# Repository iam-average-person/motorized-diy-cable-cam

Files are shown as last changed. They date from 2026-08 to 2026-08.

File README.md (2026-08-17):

 # Motorized DIY Cable Cam

A self-contained motorized cable cam system built around an Arduino Nano. Designed for small cameras. In my case I use a Insta360 One RS. Features automatic end-stop reversal, variable speed control via potentiometer, and runs entirely on a LiPo battery mounted on the carriage.
Front

## Features

- Variable speed control via potentiometer
- Automatic direction reversal at end stops (limit switches)
- 2-second pause at each end before reversing
- Dead zone at bottom of potentiometer for full stop
- Fully self-contained. Arduino, driver, battery all ride on the carriage

## Hardware

See [PARTS.md](PARTS.md) for the full parts list.

## Wiring

See the [wiring](wiring/) folder for diagram:
- [CableCamWiring.svg](wiring/CableCamWiring.svg) - Complete wiring diagram - Arduino, Buck Converter, BTS7960, LiPo Battery, potentiometer, and limit switches

## How it works

The carriage rides along a steel cable using ball bearings. A worm gear motor drives a pulley that grips the cable, propelling the carriage. Two microswitches are mounted on opposite ends of the carriage — when a striker clamp on the cable triggers a switch, the motor stops, pauses, reverses direction, and ignores the switches for 5 seconds to allow the carriage to clear the striker.

Speed is controlled by a B10K potentiometer. Turning it all the way down stops the motor completely.

## Code

The main sketch is in [cable_cam/cable_cam.ino](cable_cam/cable_cam.ino).

### Adjustable settings

| Constant | Default | Description |
|---|---|---|
| `END_PAUSE_MS` | 2000 | Pause at end stop in milliseconds |
| `MIN_PWM` | 40 | Minimum PWM to keep motor moving |
| `DEAD_ZONE_BOT` | 100 | Pot dead zone threshold (0–1023) |
| `IGNORE_MS` | 5000 | Time to ignore switches after trigger |

## Pin mapping

| Arduino pin | Connected to |
|---|---|
| D5 | RPWM (BTS7960) |
| D6 | LPWM (BTS7960) |
| D7 | R_EN (BTS7960) |
| D8 | L_EN (BTS7960) |
| D2 | Limit switch left |
| D3 | Limit switch right |
| A0 | Potentiometer wiper |
| 5V | BTS7960 VCC + buck converter output |
| GND | Shared ground rail |

## Media

Here are some images of my rig as well as a video showing some example results and what the setup looks like in action.

V1 Cable Cam Rig Example Video (Youtube-link)

Cable cam demo (https://www.youtube.com/watch?v=7-z6VbpoEs8)

V1 Cable Cam Rig In Action (Youtube-link)

Cable cam in_action (https://www.youtube.com/watch?v=ak_wcn9HPD8)

Frontview

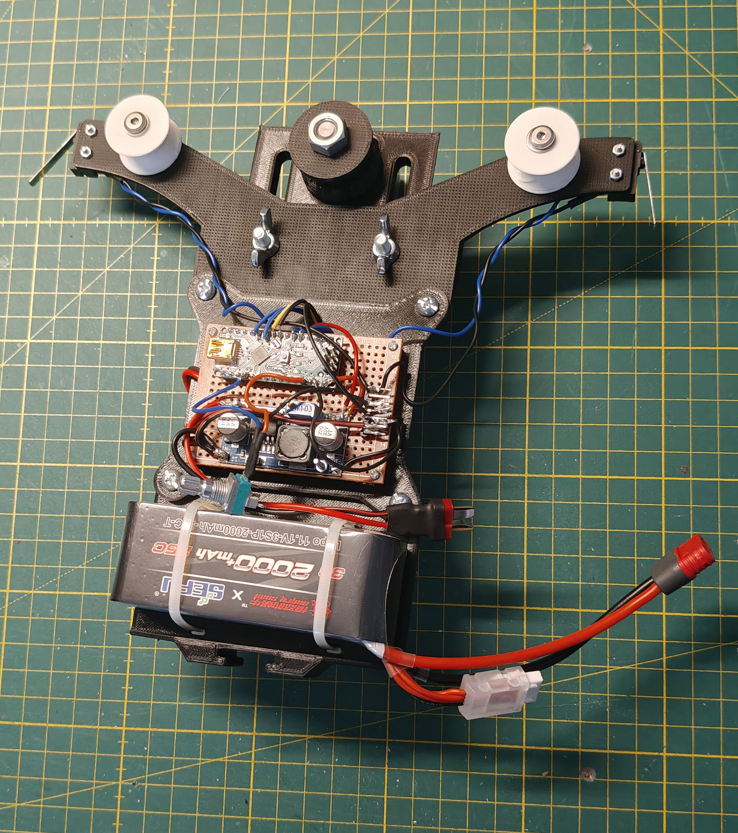
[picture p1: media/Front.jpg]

Backview

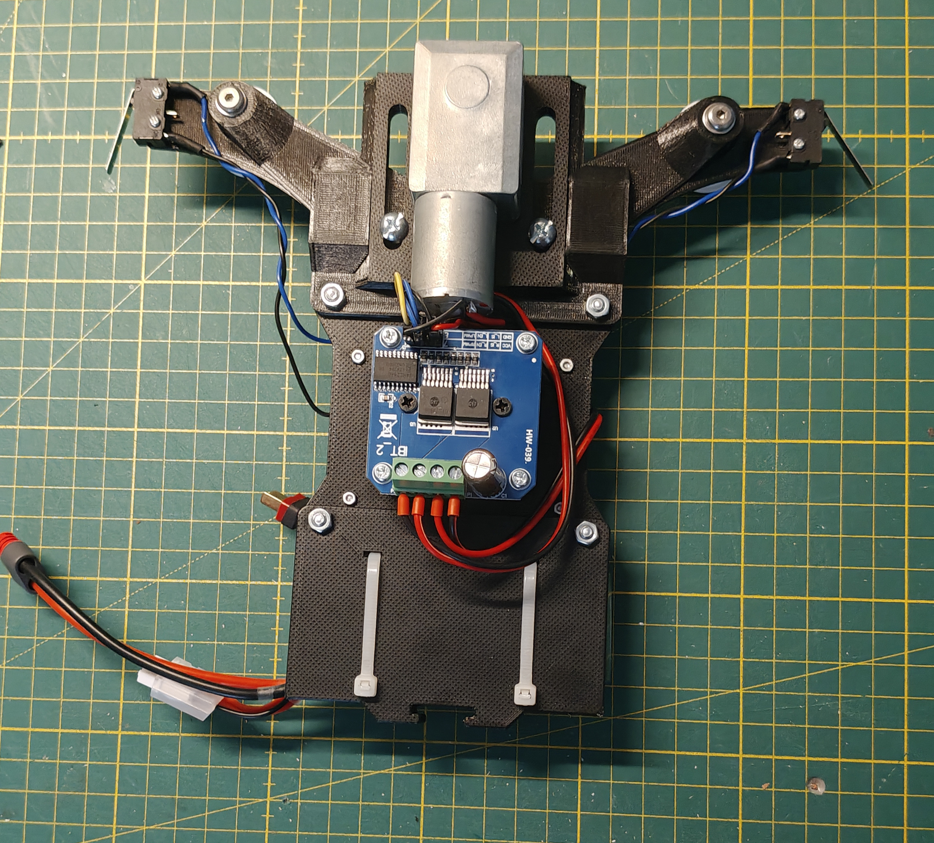
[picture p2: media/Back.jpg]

Motormounting


Pulleys

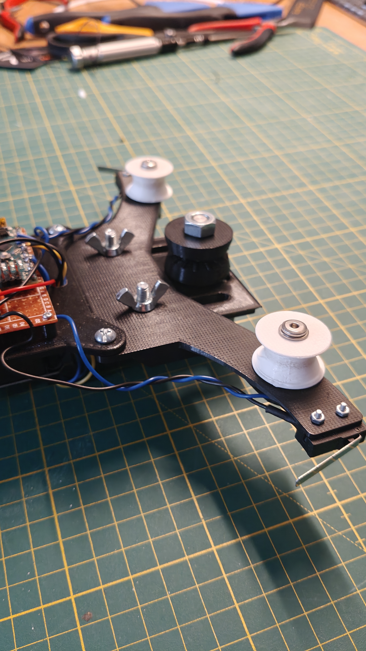
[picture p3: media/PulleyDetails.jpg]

Setup

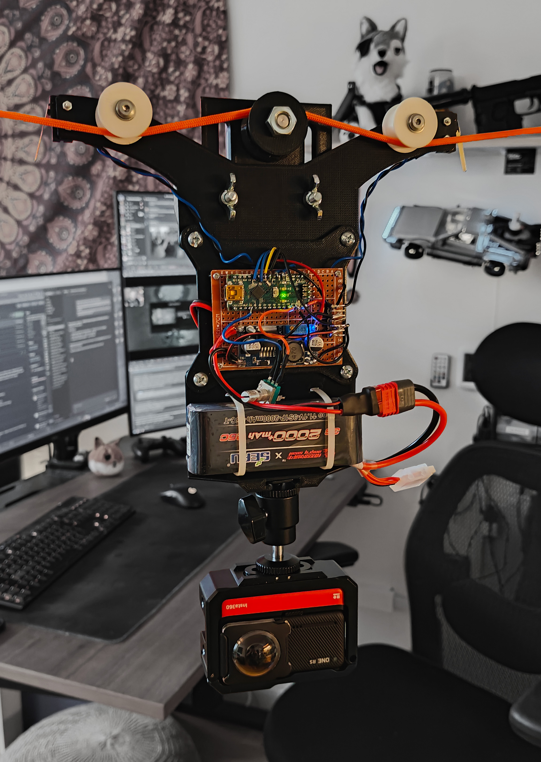
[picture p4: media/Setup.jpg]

Bag clip as endstop

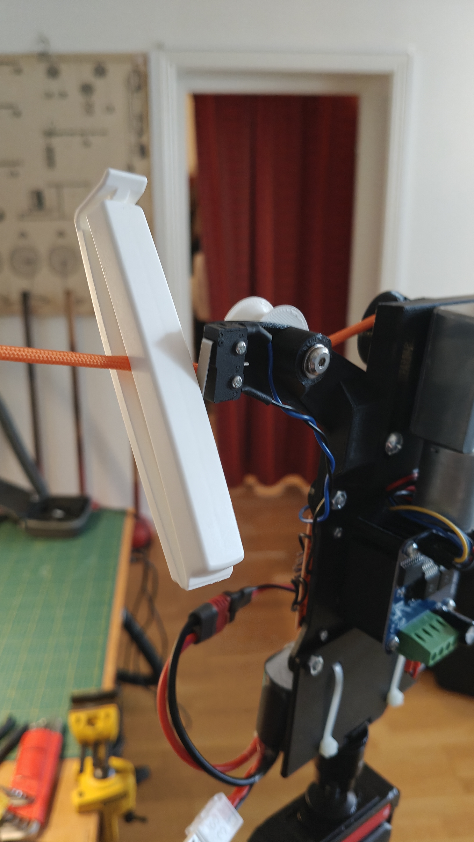
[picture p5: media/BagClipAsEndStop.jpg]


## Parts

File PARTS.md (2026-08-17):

# Parts List — Motorized DIY Cable Cam

## Electronics
 
| Component | Description | Notes |
|---|---|---|
| Arduino Nano | Microcontroller | Any V3 clone works |
| BTS7960 IBT-2 | 43A H-bridge motor driver | Handles direction + PWM speed control |
| JGY-370 | 12V worm gear motor, 40RPM | 90° output shaft, self-locking |
| LM2596 buck converter | Step-down 12V → 5V | Powers Arduino and BTS7960 logic |
| 11.1V 3S LiPo | Main battery | 2000mAh recommended |
| B10K potentiometer | Speed control | Linear taper, 10kΩ |
| Microswitch (x2) | End stop limit switches | Wired as NO (Normally Open) |

## Wiring

| Component | Notes |
|---|---|
| Jumper wires | For connecting components |
| Perfboard or PCB | For permanent mounting |
| Terminal blocks | Optional, for motor and power connections |

## Mechanical

| Component | Notes |
|---|---|
| Paracord | 2–3mm diameter, length as needed |
| Chicago Screw | For carriage to ride on cable. I used 5x30mm |
| 3D printed carriage | Custom designed |
| 3D printed pulley | Custom designed |
| Clamps for endstops | Adjustable end stop triggers on cable. Bag clips works pretty well but I will 3D-print alternatives |
| M2/M3 screws and nuts of different lengths | For assembly |
| Washers in various sizes | For assembly |

## Camera

| Component | Notes |
|---|---|
| Insta360 aluminum cage | To hold the camera |
| SmallRig Camera Cold Shoe - Ballhead-1/4" | For mounting the cage to the carriage |

## Notes

- The pulley diameter determines speed range. A 2cm pulley gives ~0.5–3 m/min at 12V. A 10cm pulley gives ~2.5–15 m/min.
- The worm gear motor is self-locking, meaning the carriage will not drift when the motor is stopped.
- The BTS7960 can handle motors up to 43A stall current, making it suitable for much larger motors if needed in the future.
- Always use a LiPo balance charger for the 3S battery.

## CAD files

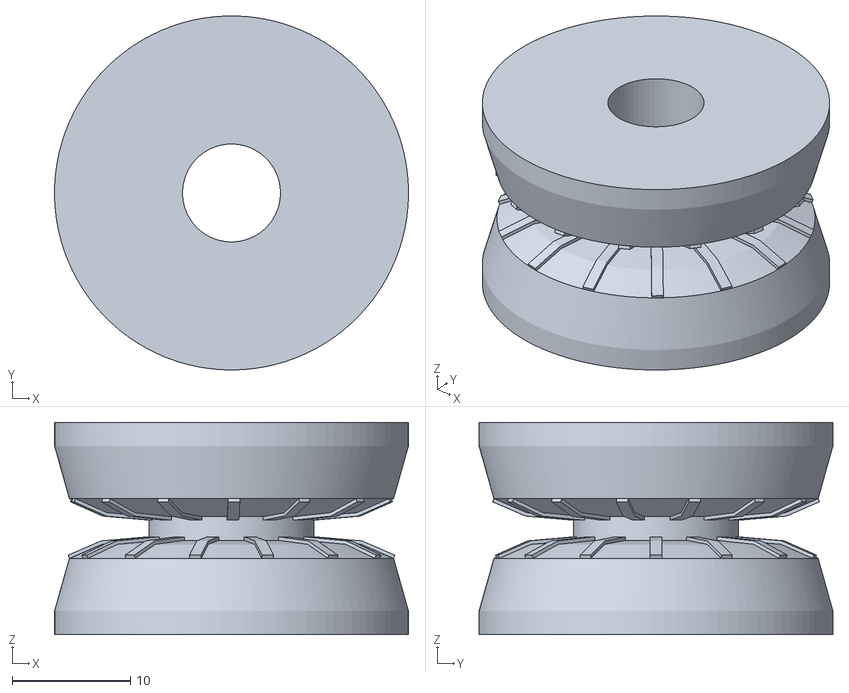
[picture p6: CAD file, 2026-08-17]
3D files/MotorPulleyFull.stl
30.0 x 30.0 x 18.0

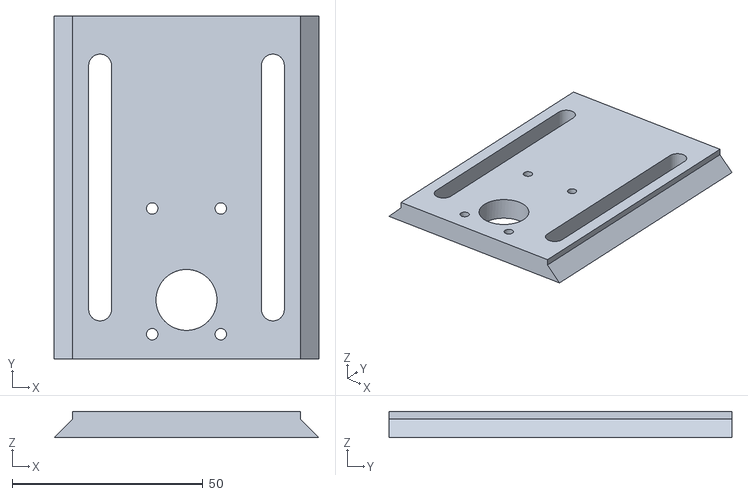
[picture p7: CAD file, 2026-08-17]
3D files/MotorSlider.stl
69.5 x 90.0 x 6.90

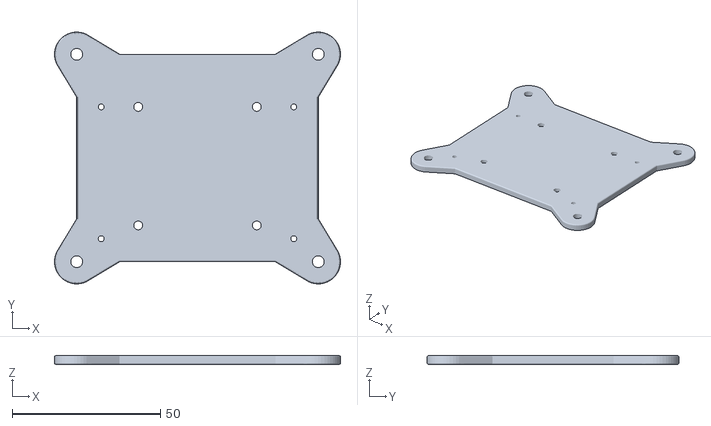
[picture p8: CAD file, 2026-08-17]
3D files/2-PCBDriverBody.stl
96.5 x 85.0 x 3.00

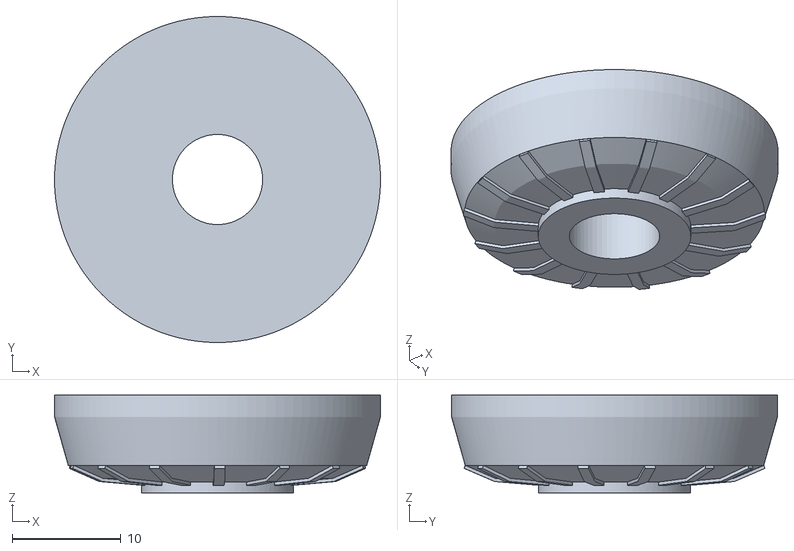
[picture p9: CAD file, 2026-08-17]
3D files/MotorPulleyHalf.stl
30.0 x 30.0 x 9.00

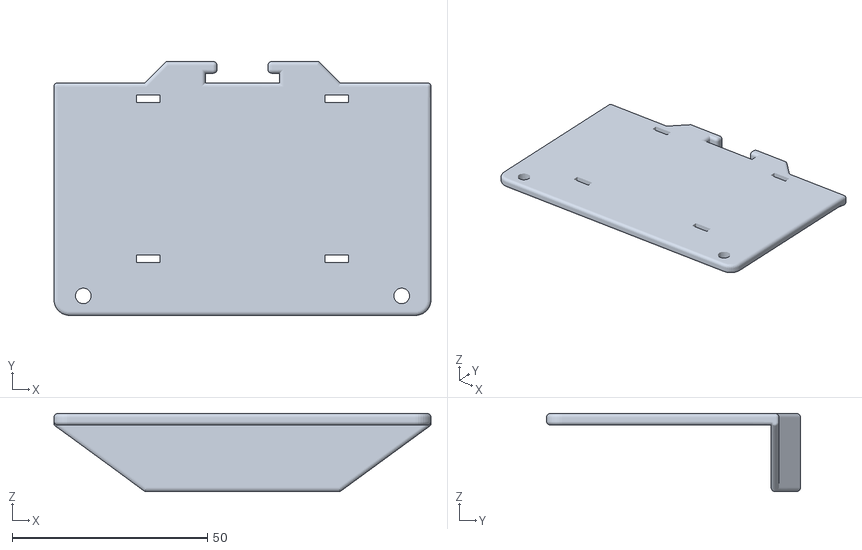
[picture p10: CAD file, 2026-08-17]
3D files/3-BatteryBody.stl
96.5 x 65.0 x 20.0

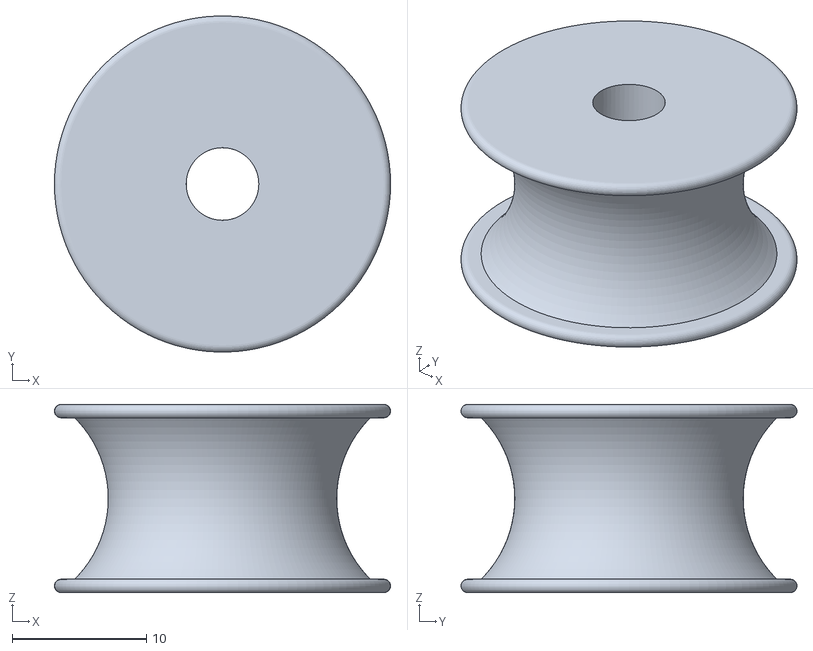
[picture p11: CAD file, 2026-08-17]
3D files/Pulley.stl
25.0 x 25.0 x 14.0

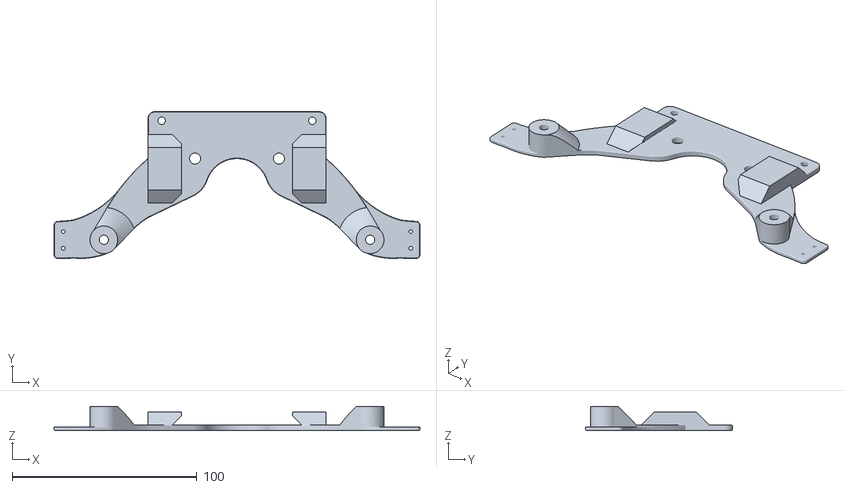
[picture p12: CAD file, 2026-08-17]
3D files/1-MotorSliderBody.stl
198.1 x 79.6 x 13.0

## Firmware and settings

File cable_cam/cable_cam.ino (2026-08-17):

// ── Pin definitions ──────────────────────────────────────
const int RPWM  = 5;   // Forward PWM
const int LPWM  = 6;   // Reverse PWM
const int R_EN  = 7;   // Forward enable
const int L_EN  = 8;   // Reverse enable
const int SW_L  = 2;   // Limit switch left  (NO, INPUT_PULLUP)
const int SW_R  = 3;   // Limit switch right (NO, INPUT_PULLUP)
const int POT   = A0;  // Potentiometer wiper

// ── Settings ─────────────────────────────────────────────
const int END_PAUSE_MS  = 2000; // Pause at end stop (ms)
const int MIN_PWM       = 40;   // Minimum PWM to keep motor moving
const int DEAD_ZONE_BOT = 100;  // Pot values 0–100 = full stop
const int IGNORE_MS     = 5000; // Ignore switches after trigger (ms)

// ── State ────────────────────────────────────────────────
int direction = 1; // 1 = forward, -1 = reverse

// ── Helpers ──────────────────────────────────────────────
void motorForward(int speed) {
  analogWrite(RPWM, speed);
  analogWrite(LPWM, 0);
}

void motorReverse(int speed) {
  analogWrite(RPWM, 0);
  analogWrite(LPWM, speed);
}

void motorStop() {
  analogWrite(RPWM, 0);
  analogWrite(LPWM, 0);
}

void runMotor(int speed) {
  if (direction == 1) motorForward(speed);
  else                motorReverse(speed);
}

int readSpeed() {
  int potVal = analogRead(POT);
  if (potVal < DEAD_ZONE_BOT) return 0;
  int speed = map(potVal, DEAD_ZONE_BOT, 1023, MIN_PWM, 255);
  return constrain(speed, MIN_PWM, 255);
}

// ── Setup ────────────────────────────────────────────────
void setup() {
  pinMode(RPWM, OUTPUT);
  pinMode(LPWM, OUTPUT);
  pinMode(R_EN, OUTPUT);
  pinMode(L_EN, OUTPUT);
  pinMode(SW_L, INPUT_PULLUP);
  pinMode(SW_R, INPUT_PULLUP);

  digitalWrite(R_EN, HIGH); // Enable forward channel
  digitalWrite(L_EN, HIGH); // Enable reverse channel
}

// ── Loop ─────────────────────────────────────────────────
void loop() {

  int speed = readSpeed();

  // Stop if pot is in dead zone
  if (speed == 0) {
    motorStop();
    return;
  }

  // Check limit switches (HIGH = triggered, NO wiring)
  bool hitLeft  = (digitalRead(SW_L) == HIGH);
  bool hitRight = (digitalRead(SW_R) == HIGH);

  if (hitLeft || hitRight) {
    motorStop();
    delay(END_PAUSE_MS);    // Pause at end
    direction = -direction; // Flip direction once

    // Run for IGNORE_MS ignoring switches so carriage clears the striker
    unsigned long ignoreUntil = millis() + IGNORE_MS;
    while (millis() < ignoreUntil) {
      int s = readSpeed();
      if (s == 0) motorStop();
      else        runMotor(s);
    }
    return;
  }

  // Run motor in current direction at pot speed
  runMotor(speed);
}
